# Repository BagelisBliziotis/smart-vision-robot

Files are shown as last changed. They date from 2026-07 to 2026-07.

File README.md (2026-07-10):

# Smart Vision Robot

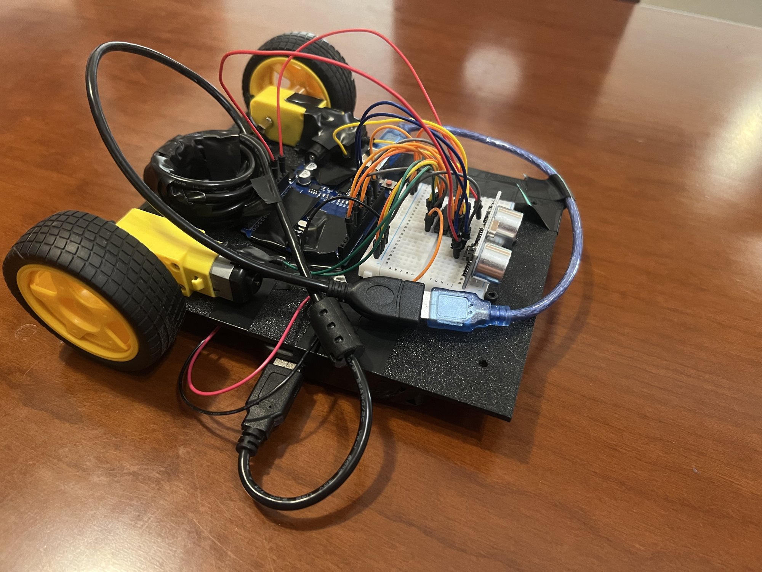
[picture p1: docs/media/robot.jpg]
Smart Vision Robot


An autonomous differential-drive robot built from scratch: 3D-printed chassis, Arduino → STM32 firmware in C, and (soon) a Raspberry Pi 5 + OpenCV vision layer. Two brains: the STM32 handles real-time reflexes, the Pi will handle seeing and thinking, talking over UART.

**Latest milestone — autonomous obstacle avoidance:** [demo video](docs/media/obstacle-avoidance.mp4)

## Progress

- [x] Chassis designed in Fusion 360, printed in PETG (v3 — see `docs/design-notes.md`)
- [x] Drive base assembled: TT gear motors + L293D H-bridge + ball caster
- [x] Untethered driving — square-drive test (Arduino) — [video](docs/media/square-drive.mp4)
- [x] Ultrasonic obstacle avoidance — fully autonomous (Arduino)
- [ ] Motor control ported to STM32 (HAL, hardware-timer PWM)
- [ ] Ultrasonic via timer input capture on STM32 (non-blocking)
- [ ] Full autonomy on STM32
- [ ] MPU-6050 IMU over I2C
- [ ] Raspberry Pi 5 + Camera Module 3: OpenCV color tracking → UART commands

## Hardware

Arduino Uno (prototype brain) · STM32 Nucleo (final real-time brain) · L293D H-bridge · 2× TT DC gear motors · HC-SR04 ultrasonic · MPU-6050 IMU · Raspberry Pi 5 4GB + Camera Module 3 · 4×AA motor supply + USB power bank · custom PETG chassis (Bambu Lab P1S)

## Why rebuild on the STM32?

The Arduino version reads the sensor with `pulseIn()`, which blocks the CPU while waiting for the echo. The STM32 rebuild measures the echo with a hardware timer in input-capture mode and generates PWM from hardware timers — non-blocking and precise, the way production embedded systems work. That rebuild is the point of the project.

## Repo map

- `firmware/arduino/` — Week 1 prototype sketches
- `firmware/stm32/` — Week 2 HAL port
- `cad/` — chassis STLs (v1–v3, see `docs/design-notes.md` for the design history)
- `docs/wiring/` — wiring photos + `connections.md`
- `docs/media/` — milestone videos and photos

## Build log

| Day | Milestone | Video |
|---|---|---|
| 5 | First untethered drive — square pattern on Arduino | [watch](docs/media/square-drive.mp4) |
| 6 | Autonomous obstacle avoidance on Arduino | [watch](docs/media/obstacle-avoidance.mp4) |

---

Built by [Bagelis Bliziotis](https://github.com/BagelisBliziotis) — ECE student at NTUA (ΣΗΜΜΥ), working toward embedded systems and robotics

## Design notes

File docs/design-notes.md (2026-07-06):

# Chassis Design Notes — Bottom Plate v2

## Overview
Differential-drive base plate, designed parametrically in Fusion 360, printed in PETG on a Bambu Lab P1S.

## Dimensions
- Plate: 150 × 120 × 3 mm, R6 rounded corners
- Coordinates below are measured from the exported STL, origin at the plate corner (0, 0)

## Features (verified from the STL)

| Feature | Qty | Ø | Positions (X, Y) |
|---|---|---|---|
| Motor mount holes (zip-tie / M3) | 8 | 3.2 mm | Left: (5,30) (5,47) (25,30) (25,47) · Right: (125,30) (125,47) (145,30) (145,47) |
| Second-deck standoff holes (M3) | 4 | 3.5 mm | (20,15) (130,15) (20,105) (130,105) → 110 × 90 mm pattern |
| Caster mount holes | 2 | 4.2 mm | (55,100) (95,100) → 40 mm spacing |

Drive axle line ≈ Y 38.5 (rear) · caster at Y ≈ 100 (front) → wheelbase ≈ 61.5 mm.

## v1 → v2 changes
- v1 (140 × 200 mm) had misaligned motor holes and excess length. v2 resized to 150 × 120 mm and re-dimensioned from actual motor measurements.
- R6 corner fillets added; 4-hole standoff pattern added for a future second deck (Raspberry Pi + electronics).

## Mounting decisions
- TT motors sit on top of the plate, held by zip ties through the Ø3.2 holes. Watch item: if the ties loosen under vibration, switch to printed L-brackets (planned fallback).
- Ball caster bolts under the front. With the motors on top, the plate bottom sits ≈ 18–19 mm above ground (66 mm wheels, axle ≈ 11 mm above the plate), which matches the caster height — no riser needed.
- The full-size breadboard (165 × 55 mm) is intentionally NOT carried on the robot — it stays on the bench for prototyping. On-robot wiring uses direct jumpers; a mini breadboard will carry the ECHO voltage divider + IMU from the STM32 phase onward.

## Print settings
PETG · 0.2 mm layers · 3 walls · 25–30 % infill · printed flat, largest face down (no supports needed)

## Superseded by v3 — see below.

## Chassis v3 (Jul 6) — final layout for this build

v2 review caught a CG problem: the power bank bay sat behind the wheel
contact line, outside the support triangle, so the robot would tip
backward under load. v2 was superseded before use. v3 keeps the same
150 × 191 × 3 mm plate but fixes it with layout instead of hardware:

- Motor zip-tie grid (Ø3.2 ×8) moved to the rear — 30 mm and 47 mm from
  the rear edge, the identical relationship it had on v1
- Caster mount unchanged at the front (Ø4.2 ×2, 40 mm apart, 20 mm from
  the front edge)
- Standoffs (Ø3.5 ×4) at x = ±55, 15 mm from front and rear edges —
  second-deck rectangle is now 110 × 161 mm
- The inserted 70 mm of mid-plate becomes the power-bank bay, now inside
  the wheel–caster support span: estimated CG ~45–50 mm ahead of the
  axle, ~60/40 wheel/caster load split
- Keeps three-point contact — no rocking, no extra parts, tipping solved
  by rearrangement rather than a second caster

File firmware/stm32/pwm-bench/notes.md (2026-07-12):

TIM4 PWM bench test — onboard LED fade via hardware timer (STM32F407G-DISC1).

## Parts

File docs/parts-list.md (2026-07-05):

# Parts List

## Owned
- STM32 Nucleo board
- Arduino Uno
- L298N motor driver
- HC-SR04 ultrasonic sensor
- MPU-6050 IMU
- DC gear motors + wheels + caster
- 1 encoder
- Raspberry Pi 5 4GB
- Camera Module 3
- Bambu Lab P1S printer
- Breadboard + jumper wires

## On order
- Pi 5 camera adapter cable (22-pin to 15-pin)
- 27W USB-C power supply
- 64GB microSD (A2)
- Pi 5 active cooler

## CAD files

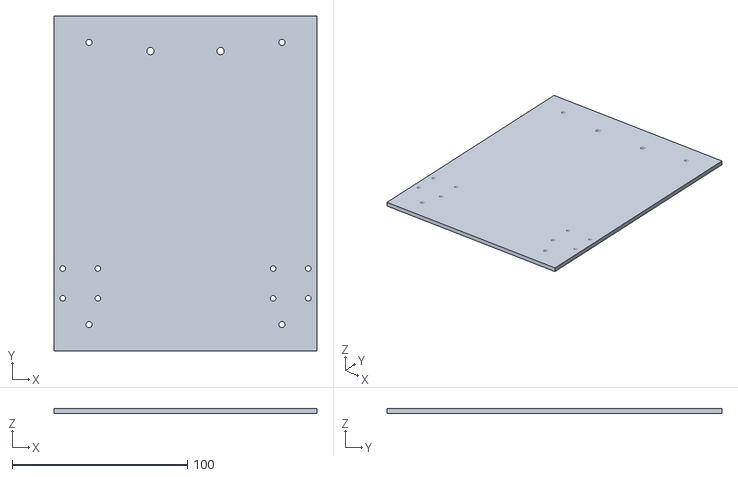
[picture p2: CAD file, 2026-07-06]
cad/chassis_bottom_plate_v3.stl
150.0 x 191.0 x 3.00

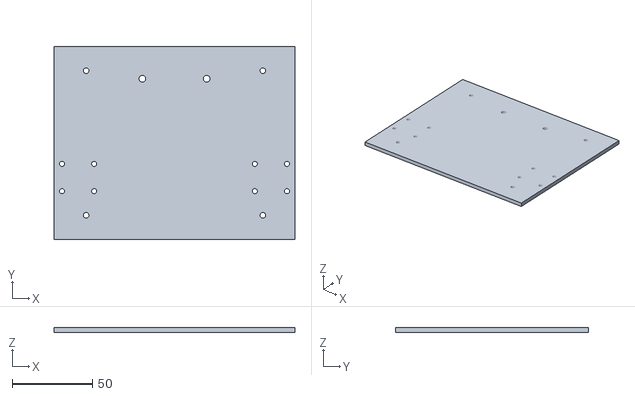
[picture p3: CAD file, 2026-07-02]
cad/chassis_bottom_plate_v2.stl.stl
150.0 x 120.0 x 3.00

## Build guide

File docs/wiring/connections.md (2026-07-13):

# Wiring — Arduino + L293D (Day 5)

## Arduino → L293D (half-size breadboard)
| Arduino | L293D pin | Function |
|---|---|---|
| D3 (PWM) | 1 (EN1) | Motor A speed |
| D4 | 2 (IN1) | Motor A direction |
| D5 | 7 (IN2) | Motor A direction |
| D6 (PWM) | 9 (EN2) | Motor B speed |
| D7 | 10 (IN3) | Motor B direction |
| D8 | 15 (IN4) | Motor B direction |
| 5V | 16 (VCC1) | Logic supply |
| GND | GND rail | Common ground |

## L293D → motors
| L293D pin | Goes to |
|---|---|
| 3 (OUT1) | Left motor terminal 1 |
| 6 (OUT2) | Left motor terminal 2 |
| 11 (OUT3) | Right motor terminal 1 |
| 14 (OUT4) | Right motor terminal 2 |
| 4, 5, 12, 13 | GND rail |

## Power
| Source | Goes to |
|---|---|
| 4×AA pack + | L293D pin 8 (VCC2, motor supply) |
| 4×AA pack − | GND rail (shared with Arduino GND) |
| USB power bank | Arduino (USB) |

## HC-SR04 ultrasonic

| HC-SR04 pin | Connects to | Notes |
|---|---|---|
| VCC | 5V rail (Arduino 5V) | ~15 mA, fine from the Arduino |
| TRIG | Arduino D9 | 10µs HIGH pulse fires the ping |
| ECHO | Arduino D10 | Direct — safe on 5V Arduino. STM32 port needs a 10k/20k divider (3.3V pin). |
| GND | Common GND rail | |

## STM32 Discovery — motor control 
EN1 (motor A speed) → PD12 (TIM4_CH1)
IN1                  → PE7
IN2                  → PE8
EN2 (motor B speed) → PD13 (TIM4_CH2)
IN3                  → PE9
IN4                  → PE10
L293D pin 16 (VCC1) → Discovery 5V
Ground               → Discovery GND, shared with battery negative

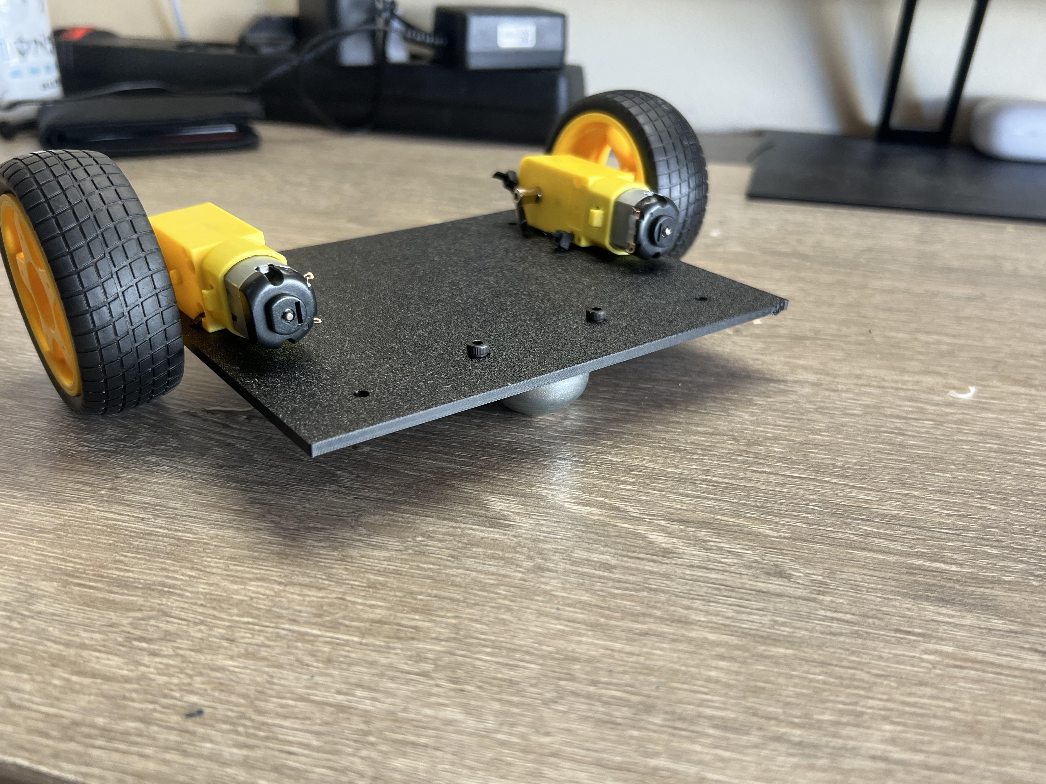
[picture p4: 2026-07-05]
docs/media/chassis.assembly.jpg

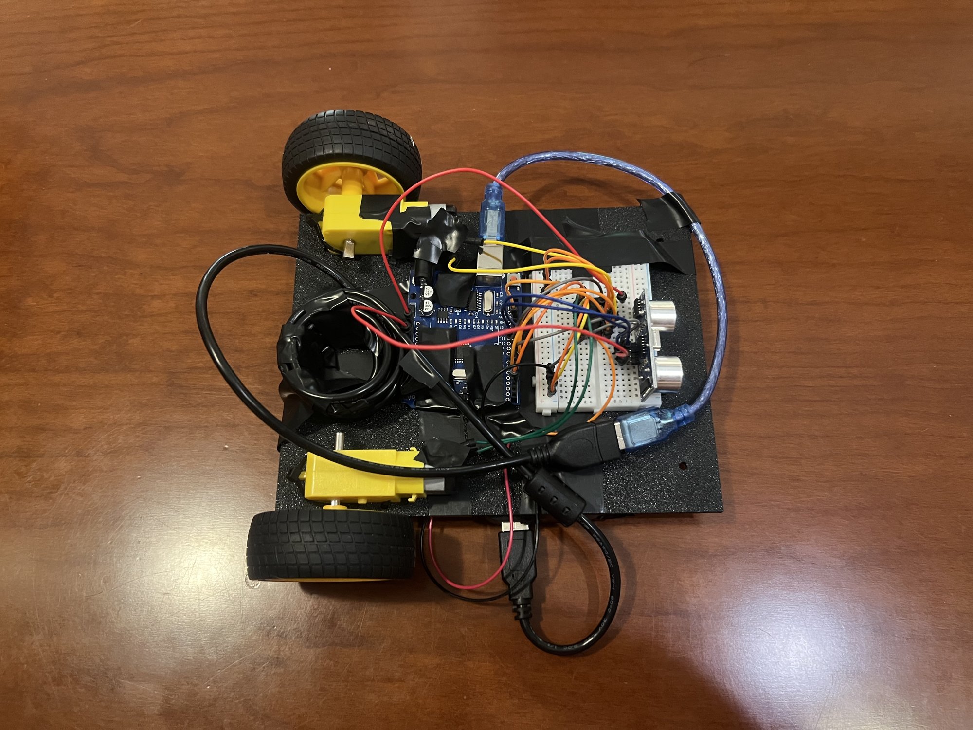
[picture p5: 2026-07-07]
docs/wiring/wiring-top.jpg

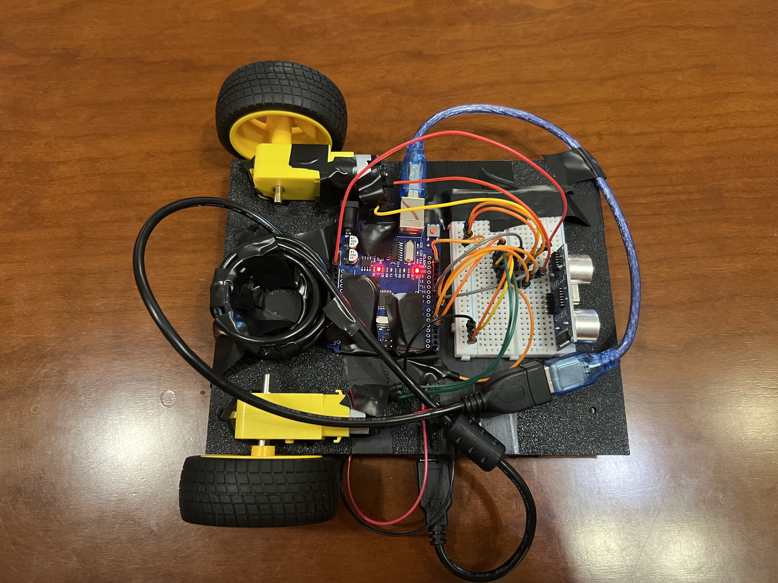
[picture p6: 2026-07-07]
docs/wiring/wiring photo(without HC-SR04).jpg

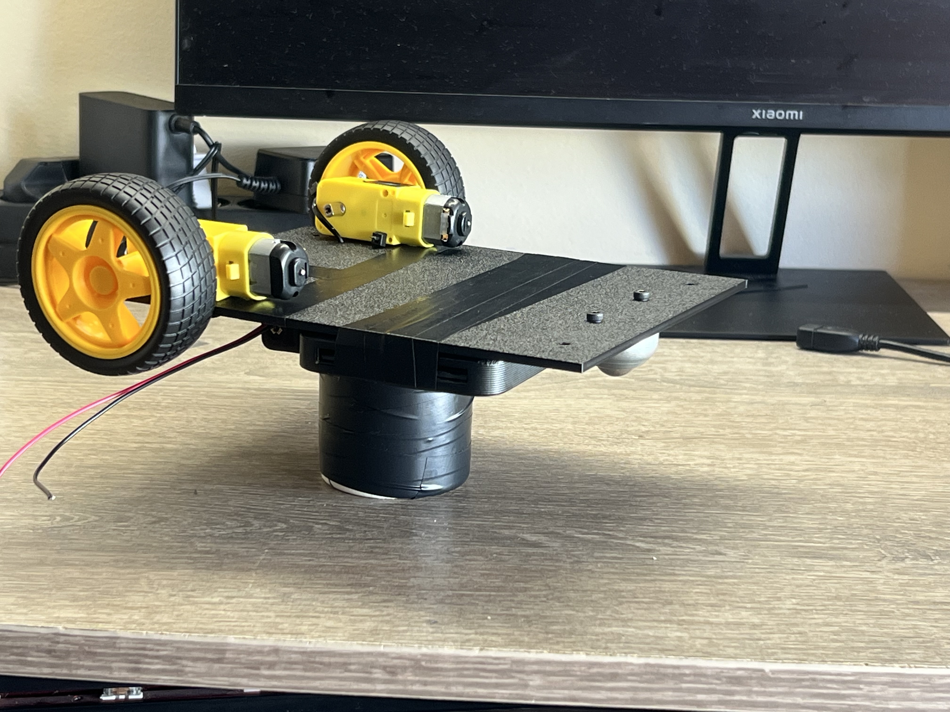
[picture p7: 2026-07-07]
docs/media/chassis-assembly-v3.jpeg

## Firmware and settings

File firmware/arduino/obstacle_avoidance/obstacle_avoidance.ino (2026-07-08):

const int EN1 = 3;   
const int IN1 = 4; 
const int IN2 = 5;   
const int EN2 = 6;   
const int IN3 = 7;   
const int IN4 = 8;   

const int TRIG = 9;
const int ECHO = 10;


const int SPEED_A = 250;     
const int SPEED_B = 250;
int  TURN_90_MS   = 670;     
const int STOP_CM    = 20;   
const int REVERSE_MS = 350;  
const int PAUSE_MS   = 150;  

void setup() {
  pinMode(EN1, OUTPUT); pinMode(IN1, OUTPUT); pinMode(IN2, OUTPUT);
  pinMode(EN2, OUTPUT); pinMode(IN3, OUTPUT); pinMode(IN4, OUTPUT);
  pinMode(TRIG, OUTPUT); pinMode(ECHO, INPUT);
  digitalWrite(TRIG, LOW);
  Serial.begin(9600);        
  stopMotors();
  delay(3000);            
}

long readDistanceCm() {
  digitalWrite(TRIG, LOW);  delayMicroseconds(2);
  digitalWrite(TRIG, HIGH); delayMicroseconds(10); 
  digitalWrite(TRIG, LOW);
  long us = pulseIn(ECHO, HIGH, 30000);  
  if (us == 0) return 999;               
  return us / 58;                        
}

void loop() {
  long d = readDistanceCm();
  Serial.println(d);

  if (d > STOP_CM) {
    forward();
  } else {
    stopMotors();  delay(PAUSE_MS);
    reverse();     delay(REVERSE_MS);
    stopMotors();  delay(PAUSE_MS);
    turnRight();   delay(TURN_90_MS);
    stopMotors();  delay(PAUSE_MS);
  }
  delay(60);   
}


void forward() {
  digitalWrite(IN1, HIGH); digitalWrite(IN2, LOW);
  digitalWrite(IN3, HIGH); digitalWrite(IN4, LOW);
  analogWrite(EN1, SPEED_A); analogWrite(EN2, SPEED_B);
}

void reverse() {
  digitalWrite(IN1, LOW); digitalWrite(IN2, HIGH);
  digitalWrite(IN3, LOW); digitalWrite(IN4, HIGH);
  analogWrite(EN1, SPEED_A); analogWrite(EN2, SPEED_B);
}

void turnLeft() {  
  digitalWrite(IN1, LOW);  digitalWrite(IN2, HIGH);
  digitalWrite(IN3, HIGH); digitalWrite(IN4, LOW);
  analogWrite(EN1, SPEED_A); analogWrite(EN2, SPEED_B);
}

void turnRight() {   
  digitalWrite(IN1, HIGH); digitalWrite(IN2, LOW);
  digitalWrite(IN3, LOW);  digitalWrite(IN4, HIGH);
  analogWrite(EN1, SPEED_A); analogWrite(EN2, SPEED_B);
}

void stopMotors() {
  analogWrite(EN1, 0); analogWrite(EN2, 0);
  digitalWrite(IN1, LOW); digitalWrite(IN2, LOW);
  digitalWrite(IN3, LOW); digitalWrite(IN4, LOW);
}

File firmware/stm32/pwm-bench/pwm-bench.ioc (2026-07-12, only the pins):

Mcu.UserName=STM32F407VGTx
PA0-WKUP.GPIO_Label=B1 [Blue PushButton]
PA0-WKUP.Signal=GPXTI0
PA10.GPIO_Label=OTG_FS_ID
PA10.Signal=USB_OTG_FS_ID
PA11.GPIO_Label=OTG_FS_DM
PA11.Signal=USB_OTG_FS_DM
PA12.GPIO_Label=OTG_FS_DP
PA12.Signal=USB_OTG_FS_DP
PA13.GPIO_Label=SWDIO
PA13.Signal=SYS_JTMS-SWDIO
PA14.GPIO_Label=SWCLK
PA14.Signal=SYS_JTCK-SWCLK
PA4.GPIO_Label=I2S3_WS [CS43L22_LRCK]
PA4.Signal=I2S3_WS
PA5.GPIO_Label=SPI1_SCK [LIS302DL_SCL/SPC]
PA5.Signal=SPI1_SCK
PA6.GPIO_Label=SPI1_MISO [LIS302DL_SDO]
PA6.Signal=SPI1_MISO
PA7.GPIO_Label=SPI1_MOSI [LIS302DL_SDA/SDI/SDO]
PA7.Signal=SPI1_MOSI
PA9.GPIO_Label=VBUS_FS
PA9.Signal=USB_OTG_FS_VBUS
PB10.GPIO_Label=CLK_IN [MP45DT02_CLK]
PB10.Signal=I2S2_CK
PB2.GPIO_Label=BOOT1
PB2.Signal=GPIO_Input
PB3.GPIO_Label=SWO
PB3.Signal=SYS_JTDO-SWO
PB6.GPIO_Label=Audio_SCL [CS43L22_SCL]
PB6.Signal=I2C1_SCL
PB9.GPIO_Label=Audio_SDA [CS43L22_SDA]
PB9.Signal=I2C1_SDA
PC0.GPIO_Label=OTG_FS_PowerSwitchOn
PC0.Signal=GPIO_Output
PC10.GPIO_Label=I2S3_SCK [CS43L22_SCLK]
PC10.Signal=I2S3_CK
PC12.GPIO_Label=I2S3_SD [CS43L22_SDIN]
PC12.Signal=I2S3_SD
PC14-OSC32_IN.GPIO_Label=PC14-OSC32_IN
PC14-OSC32_IN.Signal=RCC_OSC32_IN
PC15-OSC32_OUT.GPIO_Label=PC15-OSC32_OUT
PC15-OSC32_OUT.Signal=RCC_OSC32_OUT
PC3.GPIO_Label=PDM_OUT [MP45DT02_DOUT]
PC3.Signal=I2S2_SD
PC7.GPIO_Label=I2S3_MCK [CS43L22_MCLK]
PC7.Signal=I2S3_MCK
PD12.Signal=S_TIM4_CH1
PD13.GPIO_Label=LD3 [Orange Led]
PD13.Signal=GPIO_Output
PD14.GPIO_Label=LD5 [Red Led]
PD14.Signal=GPIO_Output
PD15.GPIO_Label=LD6 [Blue Led]
PD15.Signal=GPIO_Output
PD4.GPIO_Label=Audio_RST [CS43L22_RESET]
PD4.Signal=GPIO_Output
PD5.GPIO_Label=OTG_FS_OverCurrent
PD5.Signal=GPIO_Input
PE1.GPIO_Label=MEMS_INT2 [LIS302DL_INT2]
PE1.Signal=GPXTI1
PE3.GPIO_Label=CS_I2C/SPI [LIS302DL_CS_I2C/SPI]
PE3.Signal=GPIO_Output
PH0-OSC_IN.GPIO_Label=PH0-OSC_IN
PH0-OSC_IN.Signal=RCC_OSC_IN
PH1-OSC_OUT.GPIO_Label=PH1-OSC_OUT
PH1-OSC_OUT.Signal=RCC_OSC_OUT

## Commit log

2026-07-07 Add motor control functions for square movement
2026-07-07 Document HC-SR04 connections in connections.md
    Added connection details for HC-SR04 ultrasonic sensor.
2026-07-07 Add obstacle avoidance functionality to Arduino
    [obstacle_avoidance.ino]
2026-07-08 Fix formatting issue in obstacle_avoidance.ino
    [obstacle_avoidance.ino]
